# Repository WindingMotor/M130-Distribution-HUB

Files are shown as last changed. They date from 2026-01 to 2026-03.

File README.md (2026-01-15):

# M130-Distribution-HUB






## Overview

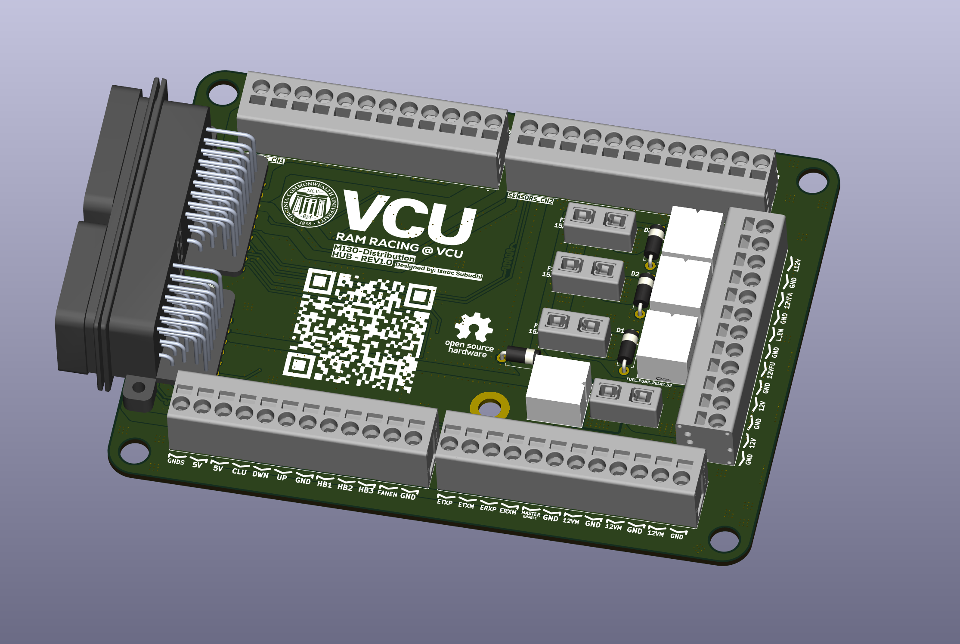
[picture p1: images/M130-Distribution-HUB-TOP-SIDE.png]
M130-Distribution-HUB PCB


The M130-Distribution-HUB provides centralized power distribution, relay control, and sensor interfacing for MoTeC M130 ECU-equipped race vehicles. Designed for Formula SAE competition with the Yamaha WR450F engine.

### Key Features

- **Direct MoTeC M130 Integration**: SuperSeal 34-pin and 26-pin connectors
- **4-Layer PCB Design**: Dual solid ground planes with optimized power distribution
- **Relay-Switched Outputs**: 4x automotive-grade SPDT relays with flyback protection
- **Individual Circuit Protection**: ATM fuse holders on each relay
- **Phoenix Contact Terminals**: Organized sensor and harness connection points
- **5V Power from MoTeC**: Eliminates need for external voltage regulation
- **FSAE Compliant**: Master shutdown relay, individual fusing, clear labeling

## Specifications

| Parameter | Value |
|---|---|
| PCB Layers | 4 (Signal, GND, GND, Signal) |
| Copper Weight | 1oz (35µm) (On each layer) |
| Board Dimensions | ~120mm x 90mm |
| Max Continuous Current | 40A (Across all relays) |
| Operating Voltage | 12V nominal (8-16V range) |
| Relay Coil Voltage | 12V DC |
| Fuse Protection | ATM blade fuses (15-30A) |
| Operating Temperature | -40°C to +95°C |
| Connector Count | 2x SuperSeal, 6x Phoenix Contact |

## PCB Component BOM

| Reference | Component | Part Number | Value | Package | Quantity |
|---|---|---|---|---|---|
| U1, U2, U3, U4 | Automotive Relay | BARK-S-112DM | 12V SPDT | Custom | 4 |
| D1, D2, D3, D4 | Flyback Diode | 1N5399 | 1.5A/1000V | DO-15 | 4 |
| F1, F2, F3, F4 | Fuse Holder | FUSE_3568 | ATM | Custom | 4 |
| CN0 | SuperSeal Connector | 6437288-3 | 34-pin + 2-pin | Custom | 1 |
| CN1-CN5 | Terminal Block | Phoenix 1190310 | 12-pos | Custom | 6 |

*Note: Fuses (15-30A ATM) not included on PCB -> user-supplied based on load requirements.*

## Relay Output Assignments

| Relay | Function | Typical Fuse Rating | Connected Load |
|---|---|---|---|
| U1 | Master Relay | 30A | Main power distribution |
| U2 | Fuel Pump Relay | 15A | Fuel pump (WR450F) |
| U3 | Lights Relay | 10A | Extra / running lights |
| U4 | Radiator Fan Relay | 15A | Engine cooling fan |

## Power Distribution

The PCB receives 12V battery & alternator power and distributes it through relay-switched outputs with individual fusing:

```
12V_BATT → Master Relay → 12V_OUT_MASTER_RELAY → Individual Load Relays → Fused Outputs
                                                → Fuel Pump
                                                → Lights
                                                → Radiator Fan
```

**5V Power**: Supplied directly from MoTeC M130 ECU 5V sensor output (no onboard regulation required). (Has dual 5V outputs at 1A Max)

## Design Features

- **Via Stitching**: Comprehensive thermal and EMI management with 4-layer stitched vias on high-current relay zones
- **Dual Ground Planes**: Solid inner layers for signal integrity and low-impedance return paths
- **Differential Pair Routing**: For CAN bus and Ethernet
- **Universal Teardrops**: PCB designed fir vibration resistance for motorsports environments
- **EMI Shielding**: Grounding via fence between high-power traces and sensitive signals
- **Conformal Coating Ready**: PCB accommodates post assembly coating for extra environmental protection

## Assembly Notes

1. **Relay Orientation**: Ensure pin 1 alignment with PCB silkscreen markings
2. **Flyback Diode Polarity**: Cathode (banded end) toward relay coil positive terminal
3. **Fuse Selection**: Size fuses per load requirements (5-30A ATM blade)
4. **Conformal Coating**: Apply MG Chemicals 422B or equivalent after assembly
5. **Mounting**: Use rubber grommets at mounting holes for vibration isolation

## Usage

1. Connect MoTeC M130 ECU via 34-pin and 26-pin SuperSeal connectors
2. Wire battery 12V and alternator 12V to main power terminals
3. Install appropriate ATM fuses in each holder per load requirements
4. Connect sensors to Phoenix Contact terminal blocks
5. Wire relay outputs to vehicle loads (fuel pump, lights, fan)
6. Configure MoTeC M130 relay enable outputs (digital outputs)

## Testing

Before vehicle installation:
- **Continuity Check**: Verify all power and ground nets
- **Isolation Test**: Confirm >10MΩ resistance between power and ground
- **Relay Function**: Enable each relays coil, verify contact closure with multimeter
- **Fuse Ratings**: Confirm proper fuse installation for each circuit

## License

This project is licensed under the **CERN Open Hardware Licence Version 2 - Permissive** (CERN-OHL-P-2.0).

You are free to:
- Use commercially
- Modify
- Distribute
- Use in closed source, with notice of changes

See [LICENSE](LICENSE) file for full terms.

## Credits

**Designed by**: RAM Racing @ VCU Formula SAE Team  
**Main Designer**: Isaac Subudhi  
**Target Vehicle**: Yamaha WR450F IC Engine  
**ECU Platform**: MoTeC M130  
**Design Tool**: KiCad 9.0

## Support

For technical questions or contributions, please open an issue or pull request.

***

**Disclaimer**: This design is provided as-is for educational and motorsports purposes. Users are responsible for validating the design meets their specific application requirements and safety standards.

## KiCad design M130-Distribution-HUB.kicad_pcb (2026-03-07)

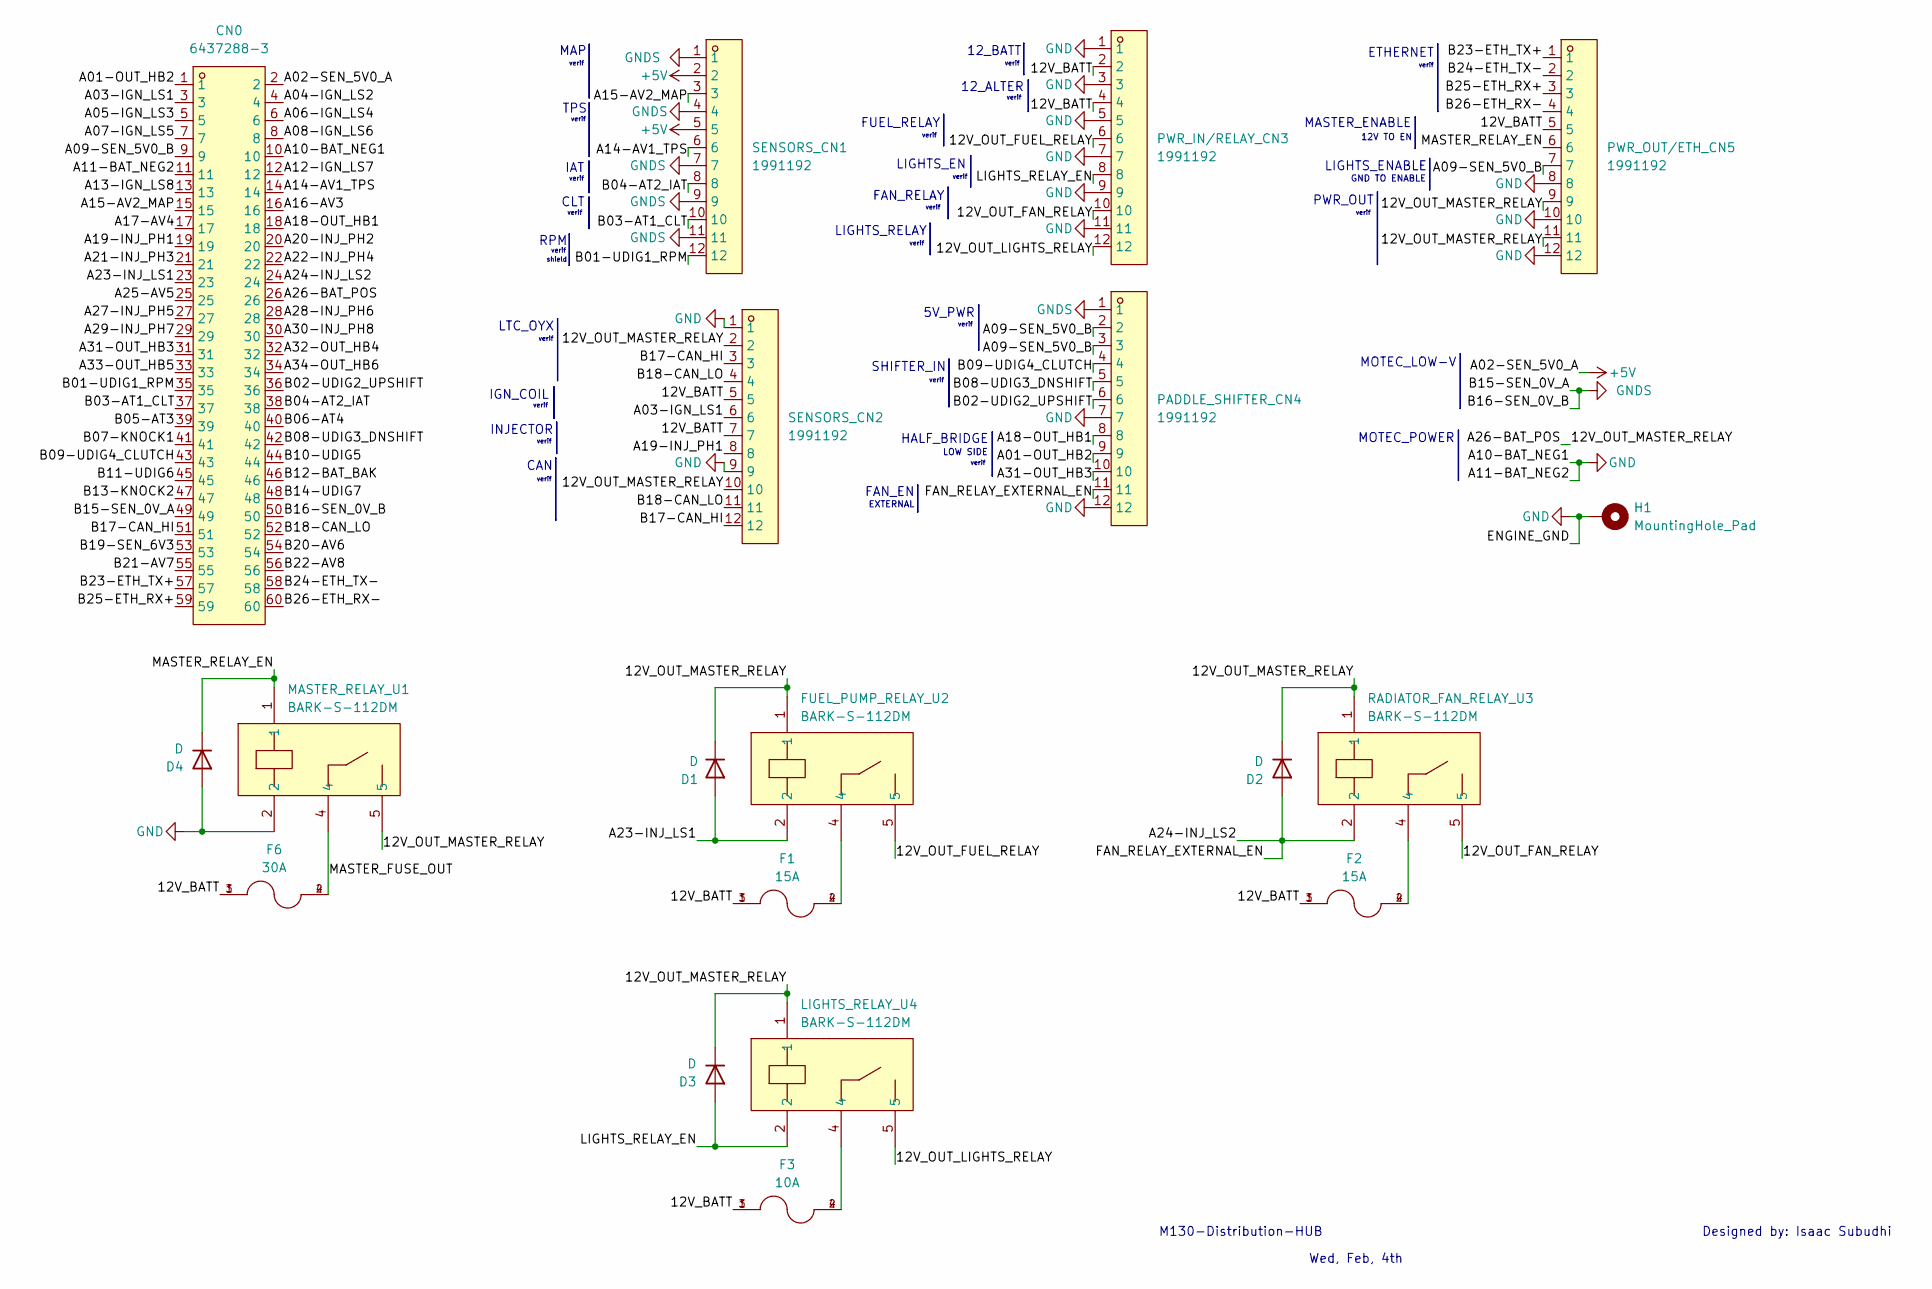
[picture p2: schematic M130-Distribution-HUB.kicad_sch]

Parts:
CN0: 6437288-3; DSUB-60P_SUPERSEAL; LCSC Part C591769
D1, D2, D3, D4: D; D_DO-15_P10.16mm_Horizontal
F1, F2: 15A; FUSE_3568; PARTREV C
F3: 10A; FUSE_3568; PARTREV C
F6: 30A; FUSE_3568; PARTREV C
FUEL_PUMP_RELAY_U2: BARK-S-112DM; RELAY-TH_BARK-S-112DM; LCSC Part C22385001
H1: MountingHole_Pad; MountingHole_5.3mm_M5_DIN965_Pad_TopBottom
LIGHTS_RELAY_U4: BARK-S-112DM; RELAY-TH_BARK-S-112DM; LCSC Part C22385001
MASTER_RELAY_U1: BARK-S-112DM; RELAY-TH_BARK-S-112DM; LCSC Part C22385001
PADDLE_SHIFTER_CN4: 1991192; PHOENIX_1991192; LCSC Part C3309553
PWR_IN/RELAY_CN3: 1991192; PHOENIX_1991192; LCSC Part C3309553
PWR_OUT/ETH_CN5: 1991192; PHOENIX_1991192; LCSC Part C3309553
RADIATOR_FAN_RELAY_U3: BARK-S-112DM; RELAY-TH_BARK-S-112DM; LCSC Part C22385001
SENSORS_CN1, SENSORS_CN2: 1991192; PHOENIX_1991192; LCSC Part C3309553

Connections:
+5V: CN0.2, SENSORS_CN1.2, SENSORS_CN1.5
/12V_BATT: F1.1, F1.3, F2.1, F2.3, F3.1, F3.3, F6.1, F6.3, PWR_IN/RELAY_CN3.2, PWR_IN/RELAY_CN3.4, PWR_OUT/ETH_CN5.5, SENSORS_CN2.5, SENSORS_CN2.7
/12V_OUT_FAN_RELAY: PWR_IN/RELAY_CN3.10, RADIATOR_FAN_RELAY_U3.5
/12V_OUT_FUEL_RELAY: FUEL_PUMP_RELAY_U2.5, PWR_IN/RELAY_CN3.6
/12V_OUT_LIGHTS_RELAY: LIGHTS_RELAY_U4.5, PWR_IN/RELAY_CN3.12
/12V_OUT_MASTER_RELAY: CN0.26, D1.1 (K), D2.1 (K), D3.1 (K), FUEL_PUMP_RELAY_U2.1, LIGHTS_RELAY_U4.1, MASTER_RELAY_U1.5, PWR_OUT/ETH_CN5.9, PWR_OUT/ETH_CN5.11, RADIATOR_FAN_RELAY_U3.1, SENSORS_CN2.2, SENSORS_CN2.10
/A01-OUT_HB2: CN0.1, PADDLE_SHIFTER_CN4.9
/A03-IGN_LS1: CN0.3, SENSORS_CN2.6
/A04-IGN_LS2: CN0.4
/A05-IGN_LS3: CN0.5
/A06-IGN_LS4: CN0.6
/A07-IGN_LS5: CN0.7
/A08-IGN_LS6: CN0.8
/A09-SEN_5V0_B: CN0.9, PADDLE_SHIFTER_CN4.2, PADDLE_SHIFTER_CN4.3, PWR_OUT/ETH_CN5.7
/A12-IGN_LS7: CN0.12
/A13-IGN_LS8: CN0.13
/A14-AV1_TPS: CN0.14, SENSORS_CN1.6
/A15-AV2_MAP: CN0.15, SENSORS_CN1.3
/A16-AV3: CN0.16
/A17-AV4: CN0.17
/A18-OUT_HB1: CN0.18, PADDLE_SHIFTER_CN4.8
/A19-INJ_PH1: CN0.19, SENSORS_CN2.8
/A20-INJ_PH2: CN0.20
/A21-INJ_PH3: CN0.21
/A22-INJ_PH4: CN0.22
/A23-INJ_LS1: CN0.23, D1.2 (A), FUEL_PUMP_RELAY_U2.2
/A24-INJ_LS2: CN0.24, D2.2 (A), PADDLE_SHIFTER_CN4.11, RADIATOR_FAN_RELAY_U3.2
/A25-AV5: CN0.25
/A27-INJ_PH5: CN0.27
/A28-INJ_PH6: CN0.28
/A29-INJ_PH7: CN0.29
/A30-INJ_PH8: CN0.30
/A31-OUT_HB3: CN0.31, PADDLE_SHIFTER_CN4.10
/A32-OUT_HB4: CN0.32
/A33-OUT_HB5: CN0.33
/A34-OUT_HB6: CN0.34
/B01-UDIG1_RPM: CN0.35, SENSORS_CN1.12
/B02-UDIG2_UPSHIFT: CN0.36, PADDLE_SHIFTER_CN4.6
/B03-AT1_CLT: CN0.37, SENSORS_CN1.10
/B04-AT2_IAT: CN0.38, SENSORS_CN1.8
/B05-AT3: CN0.39
/B06-AT4: CN0.40
/B07-KNOCK1: CN0.41
/B08-UDIG3_DNSHIFT: CN0.42, PADDLE_SHIFTER_CN4.5
/B09-UDIG4_CLUTCH: CN0.43, PADDLE_SHIFTER_CN4.4
/B10-UDIG5: CN0.44
/B11-UDIG6: CN0.45
/B12-BAT_BAK: CN0.46
/B13-KNOCK2: CN0.47
/B14-UDIG7: CN0.48
/B17-CAN_HI: CN0.51, SENSORS_CN2.3, SENSORS_CN2.12
/B18-CAN_LO: CN0.52, SENSORS_CN2.4, SENSORS_CN2.11
/B19-SEN_6V3: CN0.53
/B20-AV6: CN0.54
/B21-AV7: CN0.55
/B22-AV8: CN0.56
/B23-ETH_TX+: CN0.57, PWR_OUT/ETH_CN5.1
/B24-ETH_TX-: CN0.58, PWR_OUT/ETH_CN5.2
/B25-ETH_RX+: CN0.59, PWR_OUT/ETH_CN5.3
/B26-ETH_RX-: CN0.60, PWR_OUT/ETH_CN5.4
/LIGHTS_RELAY_EN: D3.2 (A), LIGHTS_RELAY_U4.2, PWR_IN/RELAY_CN3.8
/MASTER_FUSE_OUT: F6.2, F6.4, MASTER_RELAY_U1.4
/MASTER_RELAY_EN: D4.1 (K), MASTER_RELAY_U1.1, PWR_OUT/ETH_CN5.6
GND: CN0.10, CN0.11, D4.2 (A), H1.1, MASTER_RELAY_U1.2, PADDLE_SHIFTER_CN4.7, PADDLE_SHIFTER_CN4.12, PWR_IN/RELAY_CN3.1, PWR_IN/RELAY_CN3.3, PWR_IN/RELAY_CN3.5, PWR_IN/RELAY_CN3.7, PWR_IN/RELAY_CN3.9, PWR_IN/RELAY_CN3.11, PWR_OUT/ETH_CN5.8, PWR_OUT/ETH_CN5.10, PWR_OUT/ETH_CN5.12, SENSORS_CN2.1, SENSORS_CN2.9
GNDS: CN0.49, CN0.50, PADDLE_SHIFTER_CN4.1, SENSORS_CN1.1, SENSORS_CN1.4, SENSORS_CN1.7, SENSORS_CN1.9, SENSORS_CN1.11
unnamed: F1.2, F1.4, FUEL_PUMP_RELAY_U2.4
unnamed: F2.2, F2.4, RADIATOR_FAN_RELAY_U3.4
unnamed: F3.2, F3.4, LIGHTS_RELAY_U4.4

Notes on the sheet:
ETHERNET
LIGHTS_EN
FAN_RELAY
EXTERNAL
LOW SIDE
verif
HALF_BRIDGE
LIGHTS_RELAY
MASTER_ENABLE
LIGHTS_ENABLE
IGN_COIL
MAP
12_BATT
GND TO ENABLE
FUEL_RELAY
12_ALTER
Wed, Feb, 4th
12V TO EN
CAN
TPS
LTC_OYX
PWR_OUT
IAT
Designed by: Isaac Subudhi
shield
MOTEC_POWER
MOTEC_LOW-V
RPM
5V_PWR
M130-Distribution-HUB
SHIFTER_IN
FAN_EN
INJECTOR
CLT

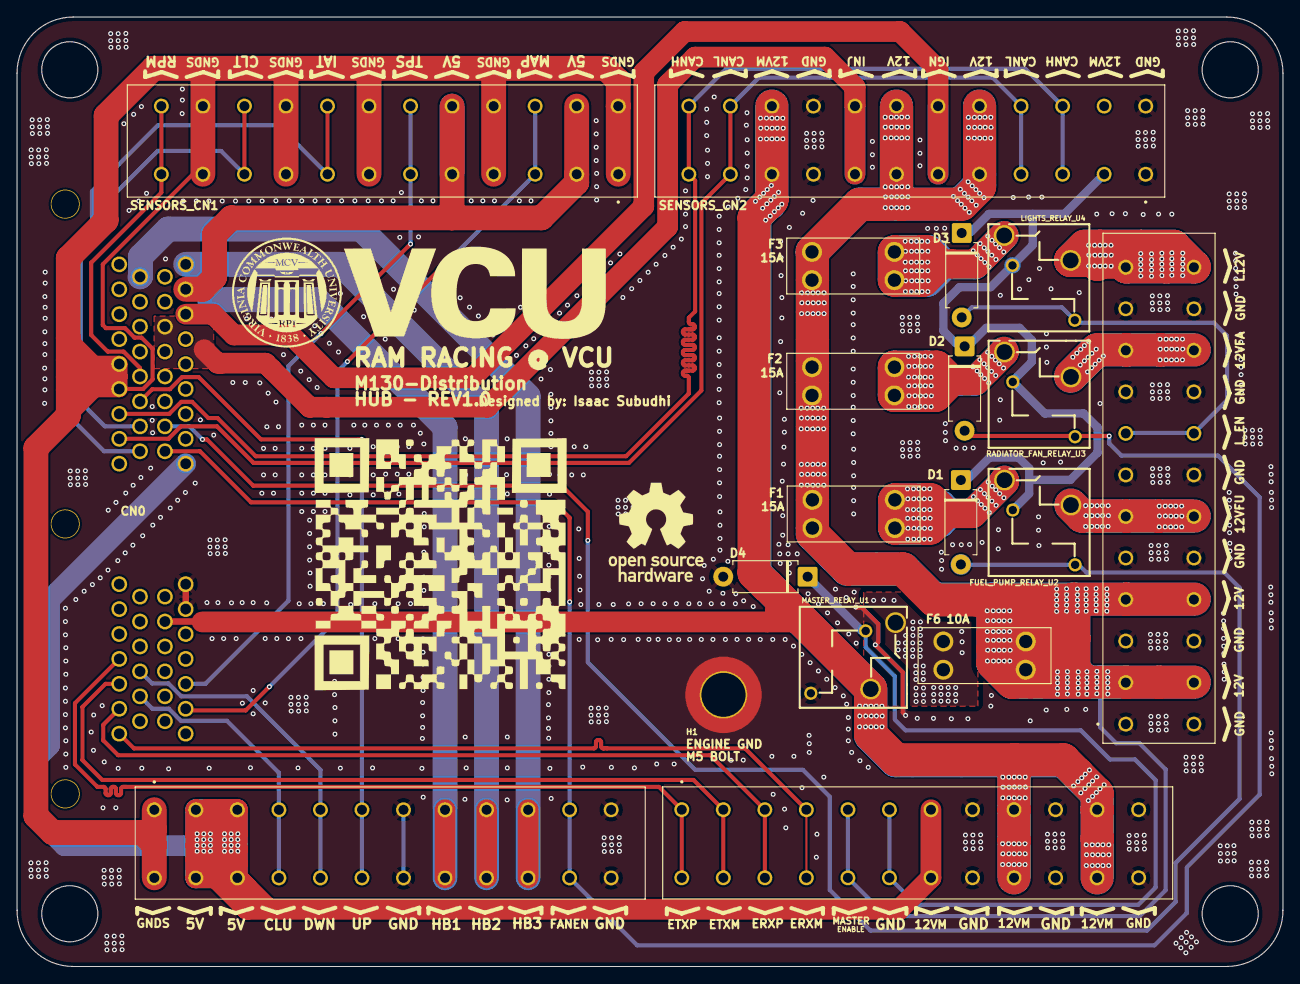
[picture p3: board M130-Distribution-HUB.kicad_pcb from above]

Board: 4 copper layers, 152.4 x 114.3 mm, 19 parts (0 on the bottom side), 36 nets.

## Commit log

2025-11-13 Init Commt
    [M130-Distribution-HUB.kicad_pcb, M130-Distribution-HUB.kicad_sch]
2025-11-13 Readme v1
    [M130-Distribution-HUB.kicad_sch]
2025-11-13 Engine GND bolt
    [M130-Distribution-HUB.kicad_pcb, M130-Distribution-HUB.kicad_sch]
2025-11-14 Top View and gerbers
    [M130-Distribution-HUB-B_Cu.gbr, M130-Distribution-HUB-B_Mask.gbr, M130-Distribution-HUB-B_Paste.gbr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]
2025-11-15 Minor changes
    [M130-Distribution-HUB.kicad_pcb]
2025-11-15 Stich via adjustments
    [M130-Distribution-HUB.kicad_pcb]
2025-12-04 Thermal relif
    [M130-Distribution-HUB.kicad_pcb, M130-Distribution-HUB.kicad_sch]
2026-01-14 Fixed DRC issues.
    [M130-Distribution-HUB-B_Cu.gbr, M130-Distribution-HUB-B_Mask.gbr, M130-Distribution-HUB-B_Paste.gbr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]
2026-01-28 Moved to vertical connectors
    [M130-Distribution-HUB-B_Cu.gbr, M130-Distribution-HUB-B_Mask.gbr, M130-Distribution-HUB-B_Paste.gbr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]
2026-02-19 Slight changes
    [M130-Distribution-HUB-B_Cu.gbr, M130-Distribution-HUB-B_Mask.gbr, M130-Distribution-HUB-B_Paste.gbr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]
2026-03-07 slight board update
    [M130-Distribution-HUB.kicad_pcb]

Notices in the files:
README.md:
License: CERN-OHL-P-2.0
